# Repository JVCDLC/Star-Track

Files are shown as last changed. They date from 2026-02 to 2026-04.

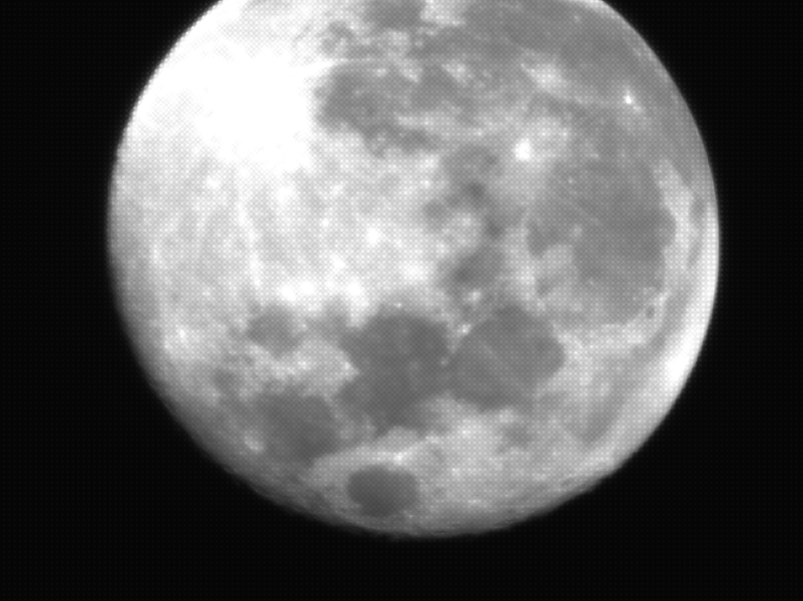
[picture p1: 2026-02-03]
Software/Raspberry Pi/Vision/Sky_Images/lune_2fev/2026-02-03-0417_0-CapObj_0000.PNG

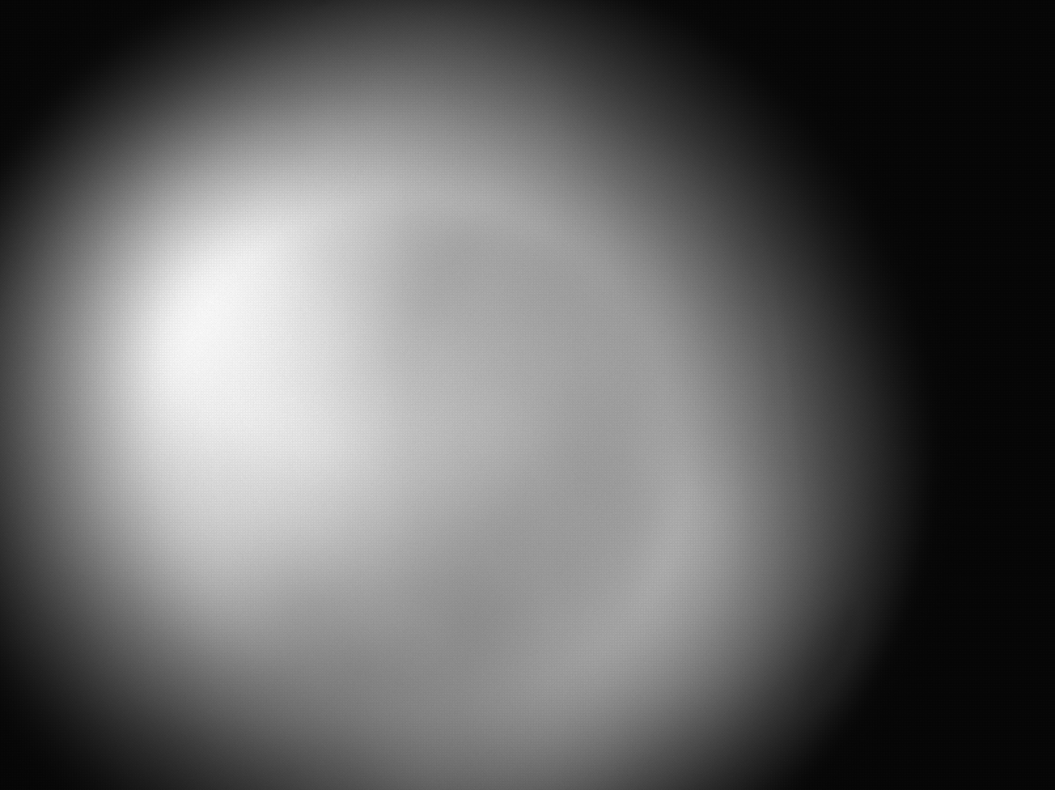
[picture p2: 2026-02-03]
Software/Raspberry Pi/Vision/Sky_Images/lune_2fev/moon_not_focus1.PNG

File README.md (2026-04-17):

# ⭐ Star-Track by JVCDLC

<p align="center">
  Star-Track preview
</p>

## 🚀 Overview

**Star-Track** is an open-source project designed to transform a **manual telescope** into a fully **automated tracking system**.

It enables you to:
- 🔭 Automatically locate stars and planets  
- 🎯 Precisely orient the telescope  
- 🔄 Track celestial objects in real time  
- 🔍 Adjust focus dynamically  

The goal is simple: make astronomical observation **faster, easier, and more accessible**.

---

## 📚 Documentation

All setup instructions, technical details, and recommendations are available in the wiki:

👉 **[Star-Track Wiki](https://github.com/JVCDLC/Star-Track/wiki)**

---

## ⚙️ Features

### 🔧 Calibration
Ensure accurate positioning and alignment of your telescope.

https://github.com/user-attachments/assets/175ef95b-0138-4629-bef2-cc6909bee551

---

### 🌐 Web Interface
Control your telescope from a clean and intuitive interface.

<p align="center">
  Web interface
</p>

---

### 🌌 Celestial Object Alignment
Automatically detect and select stars and planets.

https://github.com/user-attachments/assets/3bd77a46-6f4f-4f7e-8b46-55b38fbb0885

---

### 📡 Tracking
Keep your target centered with continuous real-time tracking.

https://github.com/user-attachments/assets/9ddb90b2-c935-49f4-bd0f-7d9df8abe6cd

---

---

## 📜 License

This project is licensed under the **GNU General Public License v2.0**.

You are free to:
- use
- modify
- distribute

as long as any derivative work is also distributed under the same license.

See the full license here: [LICENSE](./LICENSE)

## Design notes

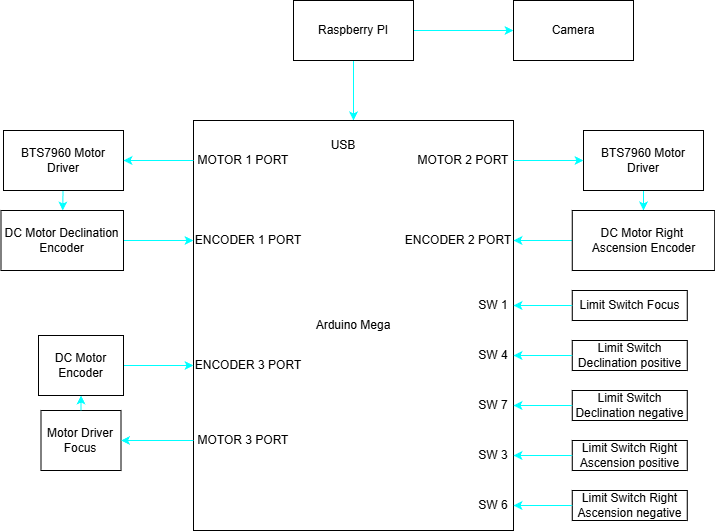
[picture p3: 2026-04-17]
Hardware/Electric shematic.png

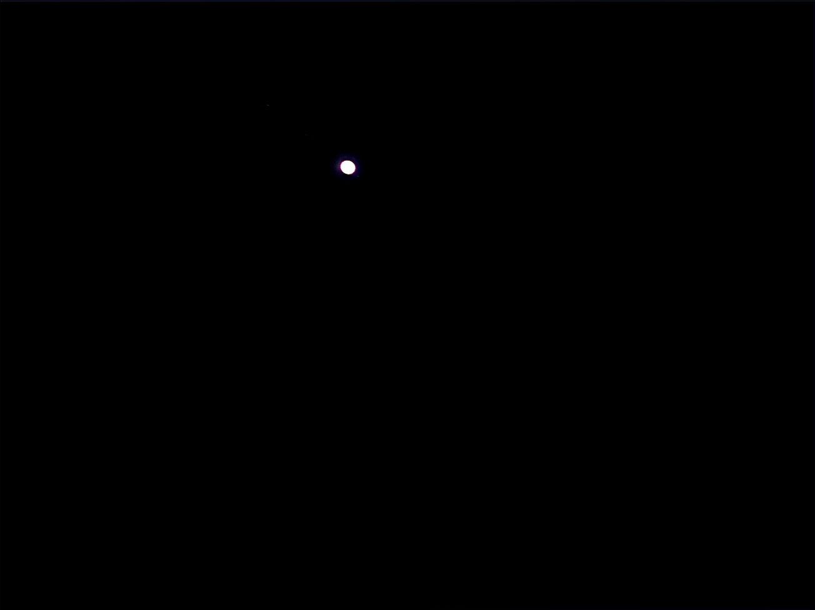
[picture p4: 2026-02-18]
Software/Raspberry Pi/Vision/Sky_Images/jupiter 13 fev/jupiter stack.jpg

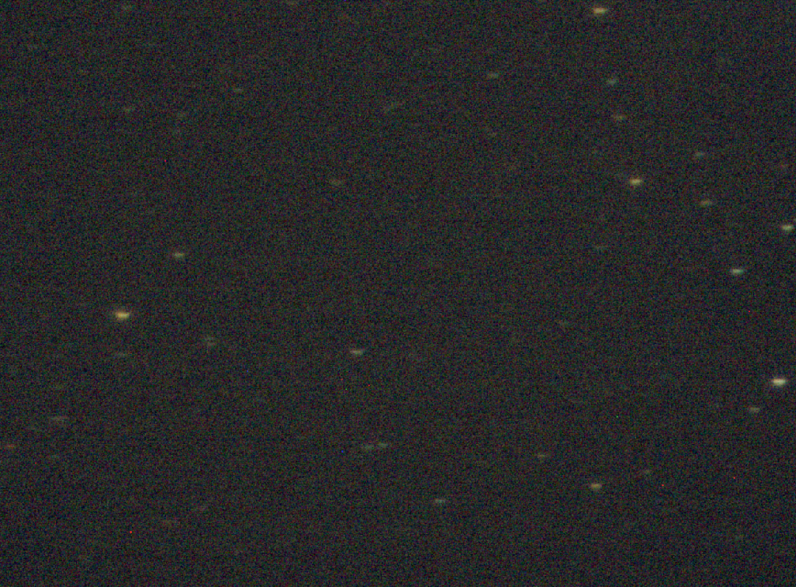
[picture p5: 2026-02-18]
Software/Raspberry Pi/Vision/Sky_Images/ciel etoile 13 fev/Capture d’écran 2026-02-13 010649.png

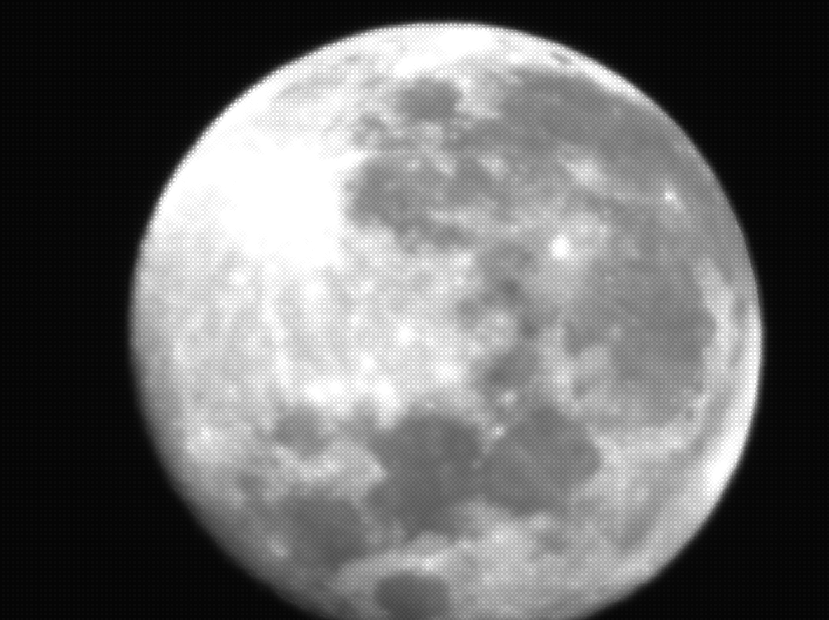
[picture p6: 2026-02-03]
Software/Raspberry Pi/Vision/Sky_Images/lune_2fev/2026-02-03-0418_9-CapObj_0000.PNG

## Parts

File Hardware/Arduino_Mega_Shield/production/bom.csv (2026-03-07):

Designator | Footprint | Quantity | Value | LCSC Part #
A1, A2, A3, A4 | Pololu_Breakout-16_15.2x20.3mm | 4 | Pololu_Breakout_A4988
A5 | Arduino_Mega2560_R3_Shield | 1 | Arduino_Mega2560_R3_Shield
BZ1 | Buzzer_12x9.5RM7.6 | 1 | Buzzer
D1 | LED_D5.0mm-4_RGB_Wide_Pins | 1 | LED_RKGB
J1, J2, J3, J4 | JST_XH_B4B-XH-A_1x04_P2.50mm_Vertical | 4 | Conn_01x04
J11 | PinHeader_1x02_P2.54mm_Vertical | 1 | SW6
J12 | PinHeader_1x02_P2.54mm_Vertical | 1 | SW7
J13 | PinHeader_1x02_P2.54mm_Vertical | 1 | SW8
J14 | PinHeader_1x02_P2.54mm_Vertical | 1 | SW9
J15, J16, J17, J18 | PinHeader_2x04_P2.54mm_Vertical | 4 | Motor Driver Connector
J19 | TerminalBlock_RND_205-00232_1x02_P5.08mm_Horizontal | 1 | Screw_Terminal_01x02
J20 | JST_XH_B4B-XH-A_1x04_P2.50mm_Vertical | 1 | JOYSTICK
J21 | JST_XH_B4B-XH-A_1x04_P2.50mm_Vertical | 1 | I2C CONNECTOR
J22 | JST_XH_B4B-XH-A_1x04_P2.50mm_Vertical | 1 | ENCODER1
J23 | JST_XH_B4B-XH-A_1x04_P2.50mm_Vertical | 1 | ENCODER2
J24 | JST_XH_B4B-XH-A_1x04_P2.50mm_Vertical | 1 | ENCODER3
J25 | JST_XH_B4B-XH-A_1x04_P2.50mm_Vertical | 1 | ENCODER4
J26 | JST_XH_B4B-XH-A_1x04_P2.50mm_Vertical | 1 | UART CONNECTOR
J27, J28, J29, J30, J31, J32, J33, J34, J35, J36, J37, J38 | 3 pin selector | 12 | 3_pin_selector
J39 | PinHeader_1x02_P2.54mm_Vertical | 1 | SW10
J5 | PinHeader_1x02_P2.54mm_Vertical | 1 | SW5
J6 | PinHeader_1x02_P2.54mm_Vertical | 1 | SW1
J7 | PinHeader_1x02_P2.54mm_Vertical | 1 | SW2
J8 | PinHeader_1x02_P2.54mm_Vertical | 1 | SW3
J9 | PinHeader_1x02_P2.54mm_Vertical | 1 | SW4
R1, R10, R2, R3, R4, R5, R6, R7, R8, R9 | R_Axial_DIN0207_L6.3mm_D2.5mm_P7.62mm_Horizontal | 10 | 10kΩ
R11, R12, R13 | R_Axial_DIN0207_L6.3mm_D2.5mm_P7.62mm_Horizontal | 3 | 220Ω

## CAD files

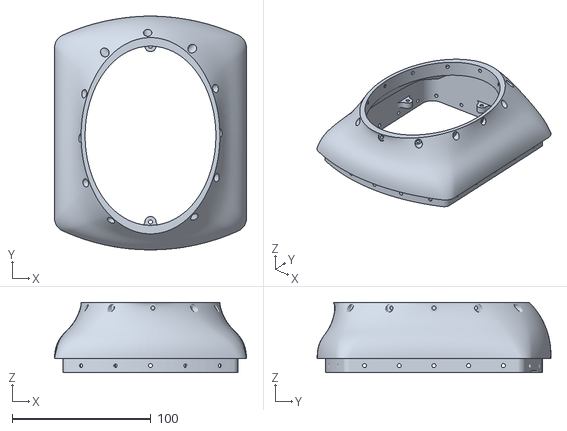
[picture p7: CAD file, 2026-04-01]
3D prints files/009 - TRIPOD BRACKET/LINK MAIN BASE TO MIDDLE ELBOW.stl
138.3 x 168.4 x 50.6

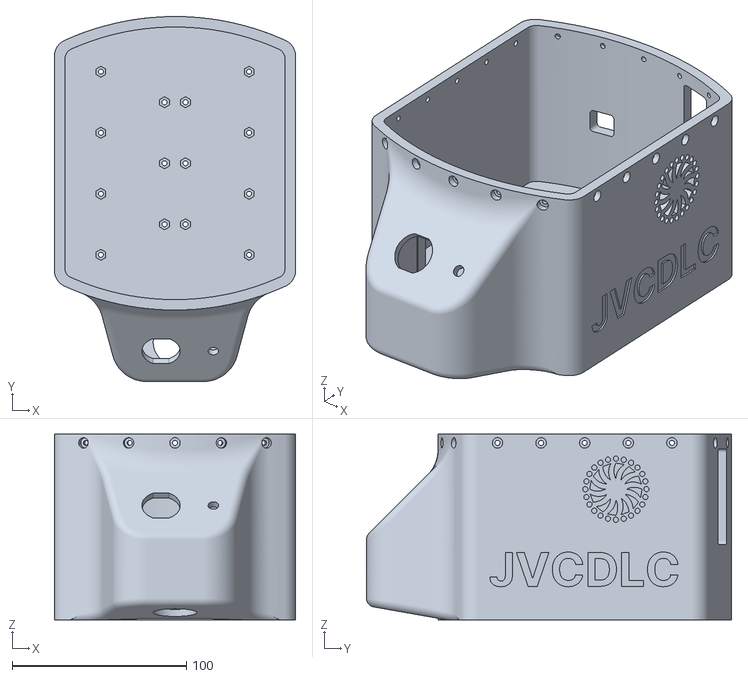
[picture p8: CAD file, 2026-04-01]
3D prints files/009 - TRIPOD BRACKET/MAIN BASE.stl
138.3 x 209.3 x 106.4

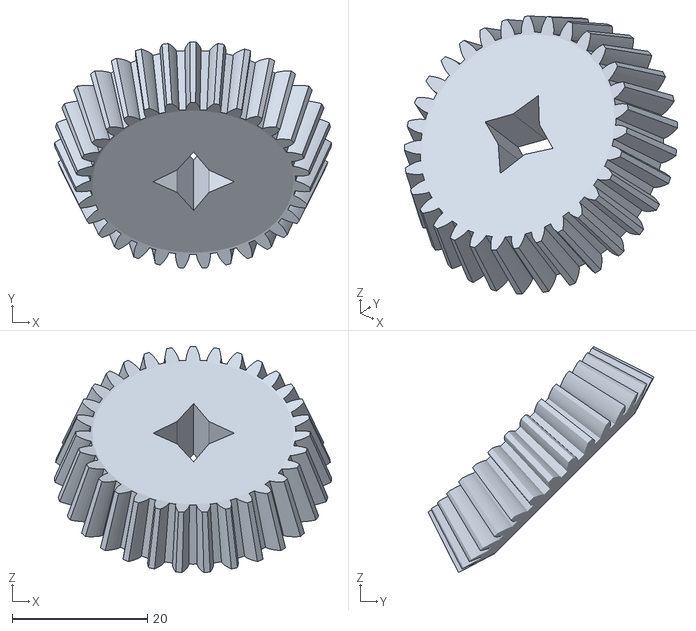
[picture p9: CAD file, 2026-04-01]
3D prints files/005 - FOCUS/MOTOR GEAR.stl
40.9 x 33.4 x 33.4

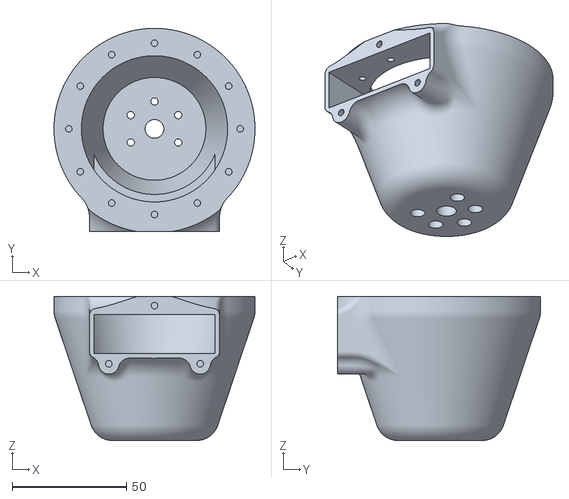
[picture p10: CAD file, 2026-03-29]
3D prints files/007 - GEARBOX JOINT/COUNTER WEIGHT HOLDER.stl
88.0 x 89.0 x 63.1

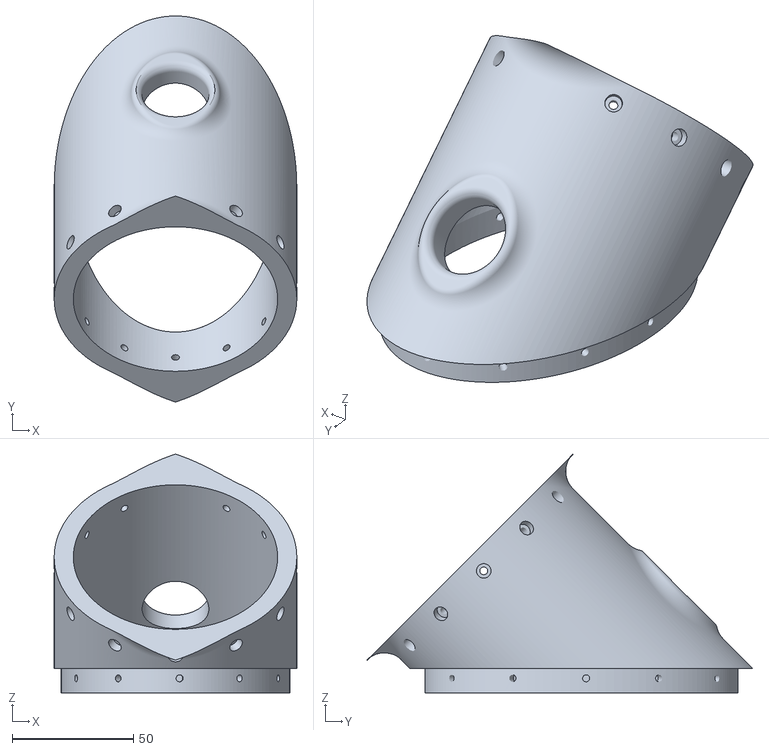
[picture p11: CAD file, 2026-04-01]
3D prints files/009 - TRIPOD BRACKET/MIDDLE BASE ELBOW.stl
100.0 x 159.1 x 98.4

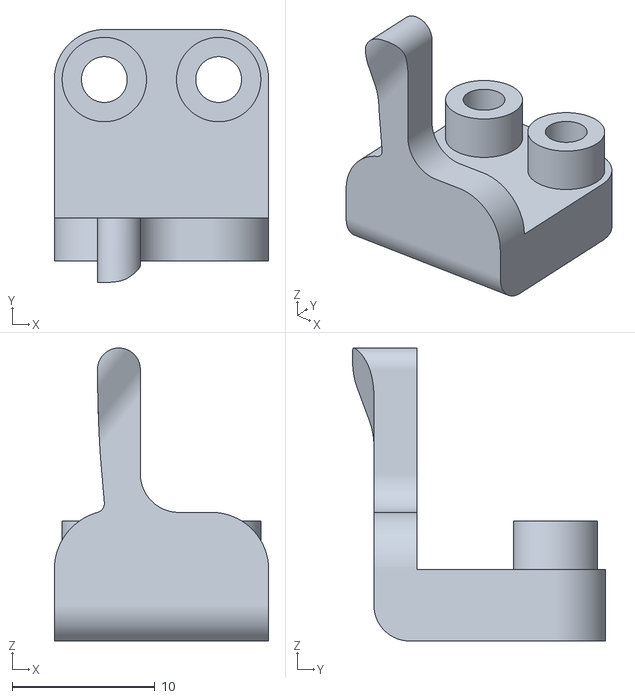
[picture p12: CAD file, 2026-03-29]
3D prints files/012 - LIMIT SWITCH/LEFT STOPPER.stl
15.0 x 17.7 x 20.5

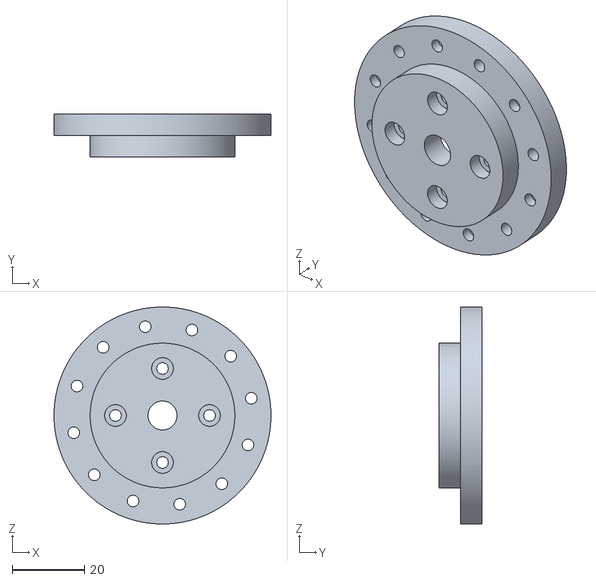
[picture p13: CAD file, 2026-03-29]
3D prints files/014 - CYCLOIDAL GEARBOX/DEC MOTOR MOUNT A.stl
60.0 x 12.0 x 60.0

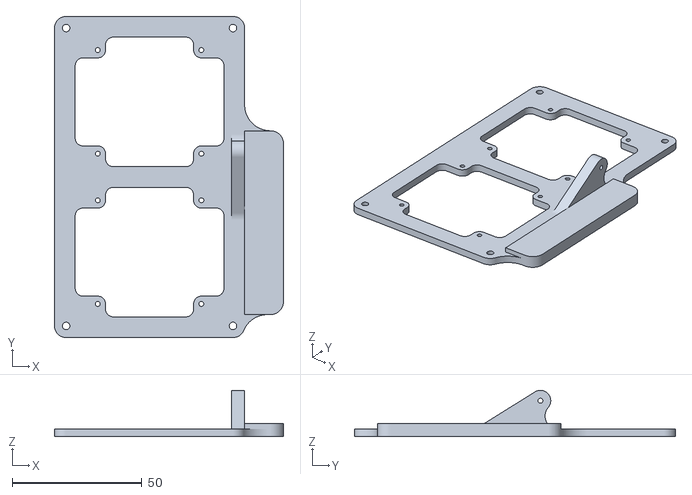
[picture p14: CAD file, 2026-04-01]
3D prints files/015 - ELECTRICAL SKELETON/UPPER PLATE.stl
88.4 x 124.0 x 17.9

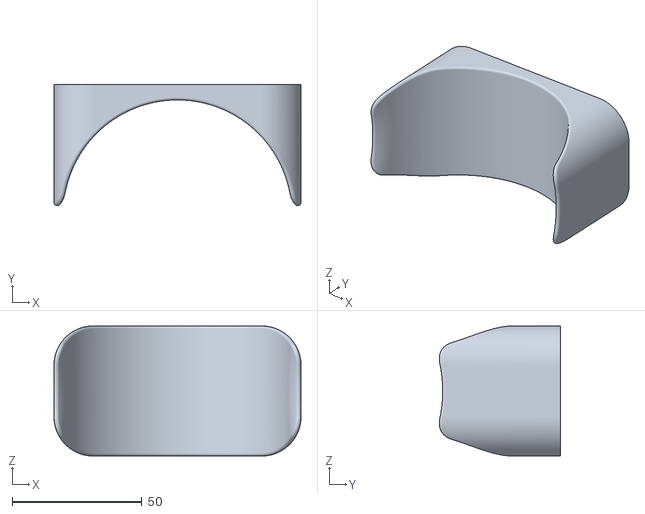
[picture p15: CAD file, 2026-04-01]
3D prints files/OTHER/HOLDER.stl
95.0 x 46.7 x 50.0

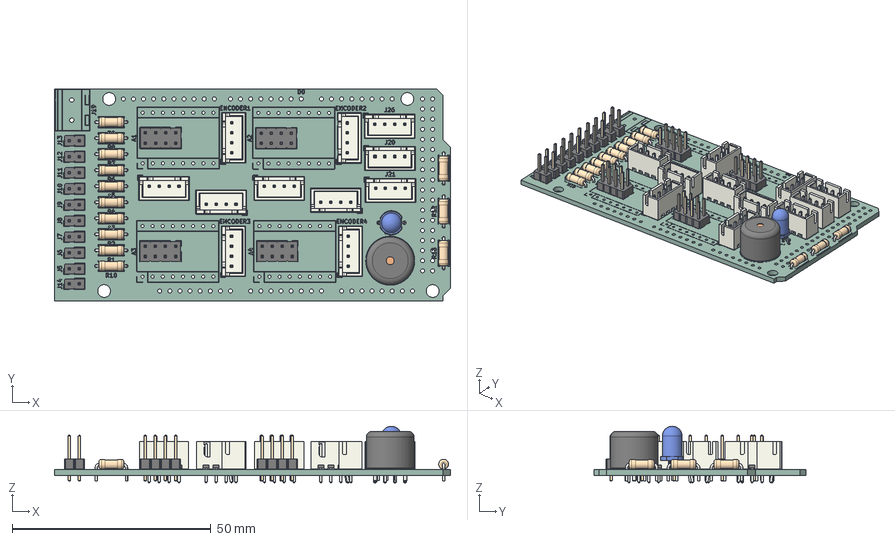
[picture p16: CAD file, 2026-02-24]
Hardware/Arduino_Mega_Shield/Arduino_Mega_Shield.step
99.5 x 53.3 x 14.2 mm
JST_XH_B4B-XH-A_1x04_P2.50mm_Vertical x 11
PinHeader_1x02_P2.54mm_Vertical x 10
LED_D5.0mm-4_RGB_Wide_Pins
R_Axial_DIN0207_L6.3mm_D2.5mm_P7.62mm_Horizontal x 13
PinHeader_2x04_P2.54mm_Vertical x 4
Buzzer_12x9.5RM7.6
Arduino_Mega_Shield_silkscreen x 2
Arduino_Mega_Shield_PCB

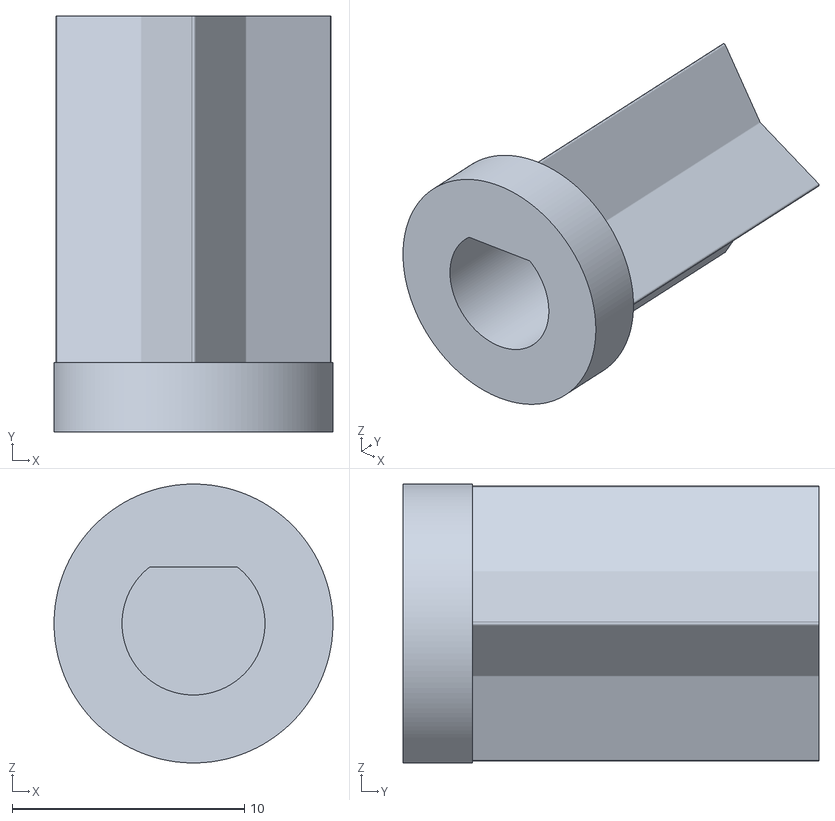
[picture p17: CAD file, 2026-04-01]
3D prints files/005 - FOCUS/SHAFT COUPLING SPLINE.stl
12.0 x 17.9 x 12.0

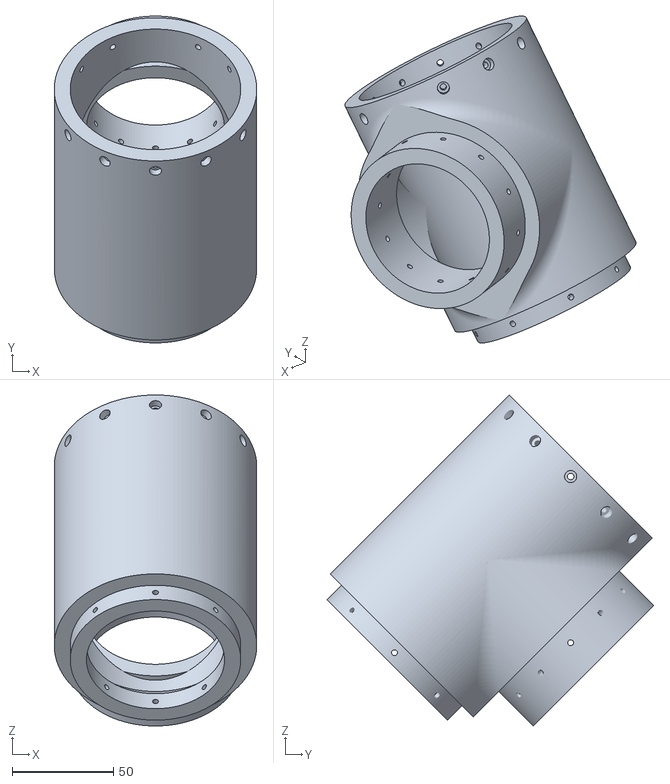
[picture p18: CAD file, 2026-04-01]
3D prints files/009 - TRIPOD BRACKET/ELBOW TO RA GEARBOX.stl
100.0 x 161.4 x 163.5

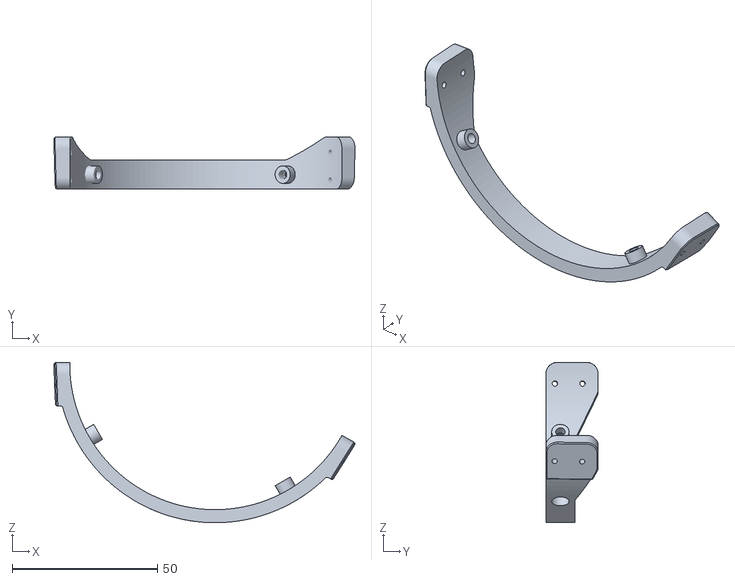
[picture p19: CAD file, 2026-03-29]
3D prints files/012 - LIMIT SWITCH/RA LIMIT SWITCH HOLDER.stl
103.6 x 18.0 x 55.2

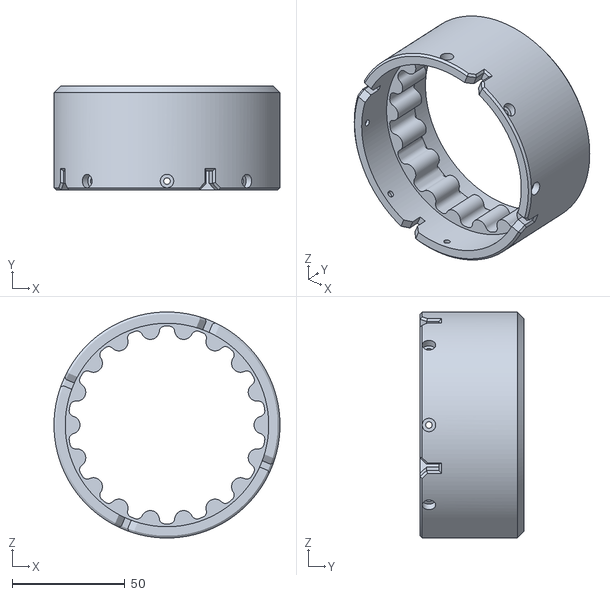
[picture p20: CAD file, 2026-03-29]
3D prints files/014 - CYCLOIDAL GEARBOX/DEC ROTOR.stl
100.0 x 46.1 x 100.0

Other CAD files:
3D prints files/015 - ELECTRICAL SKELETON/LOWER PLATE.stl
3D prints files/OTHER/TELESCOPE MOUNT.stl
3D prints files/005 - FOCUS/FOCUS MOTOR BRACKET.stl
3D prints files/007 - GEARBOX JOINT/BAR HOLDER.stl
3D prints files/005 - FOCUS/FOCUS TELESCOPE BRACKET.stl
3D prints files/005 - FOCUS/TELESCOPE WHEEL GEAR.stl
3D prints files/007 - GEARBOX JOINT/(2X) SIDE COVER PLATE.stl
3D prints files/007 - GEARBOX JOINT/(2X) TOP LOWER PLATE.stl
3D prints files/007 - GEARBOX JOINT/(6X) SCREW BLOCK.stl
3D prints files/007 - GEARBOX JOINT/FRONT COVER PLATE.stl
3D prints files/007 - GEARBOX JOINT/MOUNTING PLATE.stl
3D prints files/009 - TRIPOD BRACKET/ELBOW TO RA GEARBOX JOINT.stl
3D prints files/009 - TRIPOD BRACKET/POWER CABLE PLUG.stl
3D prints files/009 - TRIPOD BRACKET/RA GEARBOX BRACKET.stl
3D prints files/009 - TRIPOD BRACKET/RA MOTOR CAP.stl
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

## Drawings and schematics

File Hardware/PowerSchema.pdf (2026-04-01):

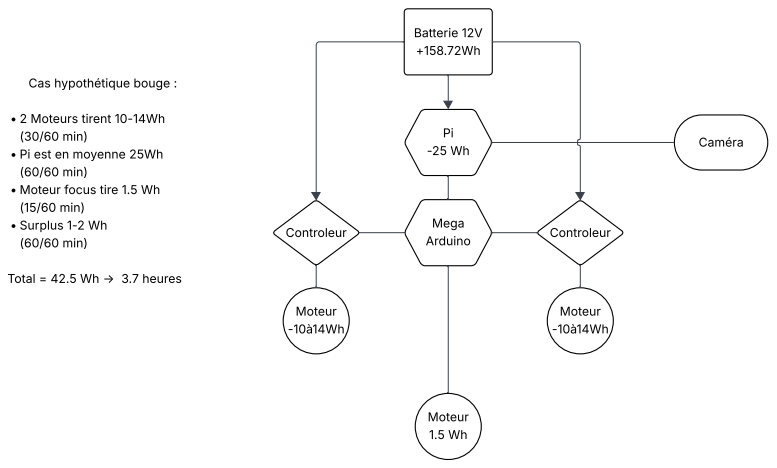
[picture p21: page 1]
Batterie 12V +158.72Wh; Controleur; Moteur -10à14Wh; Moteur 1.5 Wh; Mega Arduino; Caméra

Cas hypothétique bouge :

- 2 Moteurs tirent 10-14Wh
(30/60 min)
- Pi est en moyenne 25Wh
(60/60 min)
- Moteur focus tire 1.5 Wh
(15/60 min)
- Surplus 1-2 Wh

Total = 42.5 Wh ? 3.7 heures

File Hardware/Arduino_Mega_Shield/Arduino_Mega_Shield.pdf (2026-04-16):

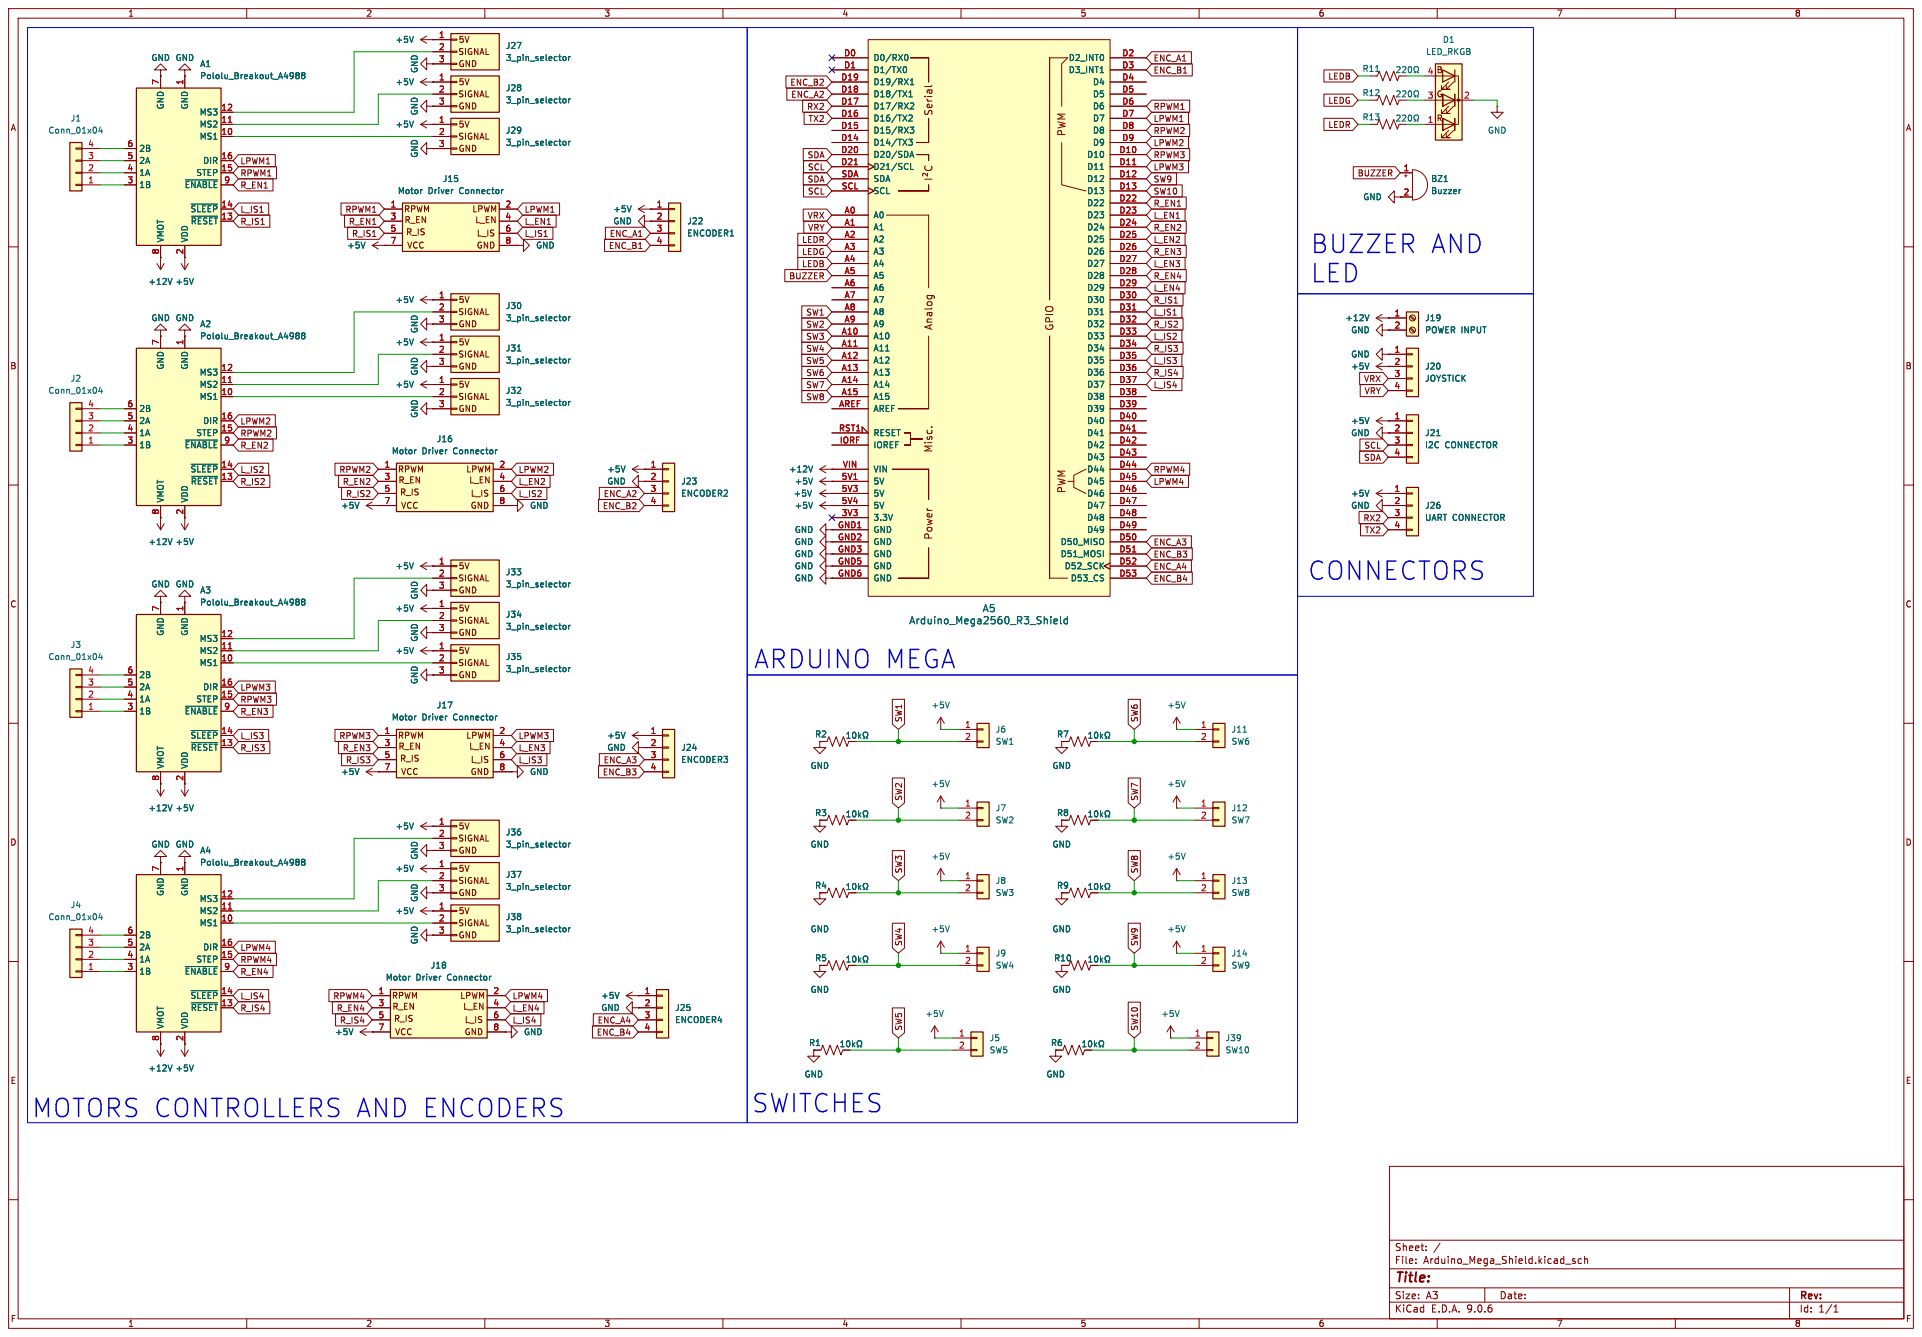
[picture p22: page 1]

GND
BUZZER AND
LED
J19 POWER INPUT GND GND

~{RESET} 13 ~{SLEEP} 14 ~{ENABLE}9 STEP 15 DIR 16 MS1 10 MS2 11 MS3 12 VDD 2 GND 1 VMOT 8 GND 7

J19 POWER INPUT 12 GND GND

A2Pololu_Breakout_A4988 ~{RESET} 13 ~{SLEEP} 14 ~{ENABLE}9 STEP 15 DIR 16 MS1 10 MS2 11 MS3 12 VDD 2 GND 1 VMOT 8 GND 7

J17 Motor Driver Connector GND

3_pin_selector GND GND
A3Pololu_Breakout_A4988 ~{RESET} 13 ~{SLEEP} 14 ~{ENABLE}9 STEP 15 DIR 16 MS1 10 MS2 11 MS3 12 VDD 2 GND 1 VMOT 8 GND 7

Id: 1/1 Title: File: Arduino_Mega_Shield.kicad_sch Sheet: / 12

A4Pololu_Breakout_A4988 ~{RESET} 13 ~{SLEEP} 14 ~{ENABLE}9 STEP 15 DIR 16 MS1 10 MS2 11 MS3 12 VDD 2 GND 1 VMOT 8 GND 7

MOTORS CONTROLLERS AND ENCODERS

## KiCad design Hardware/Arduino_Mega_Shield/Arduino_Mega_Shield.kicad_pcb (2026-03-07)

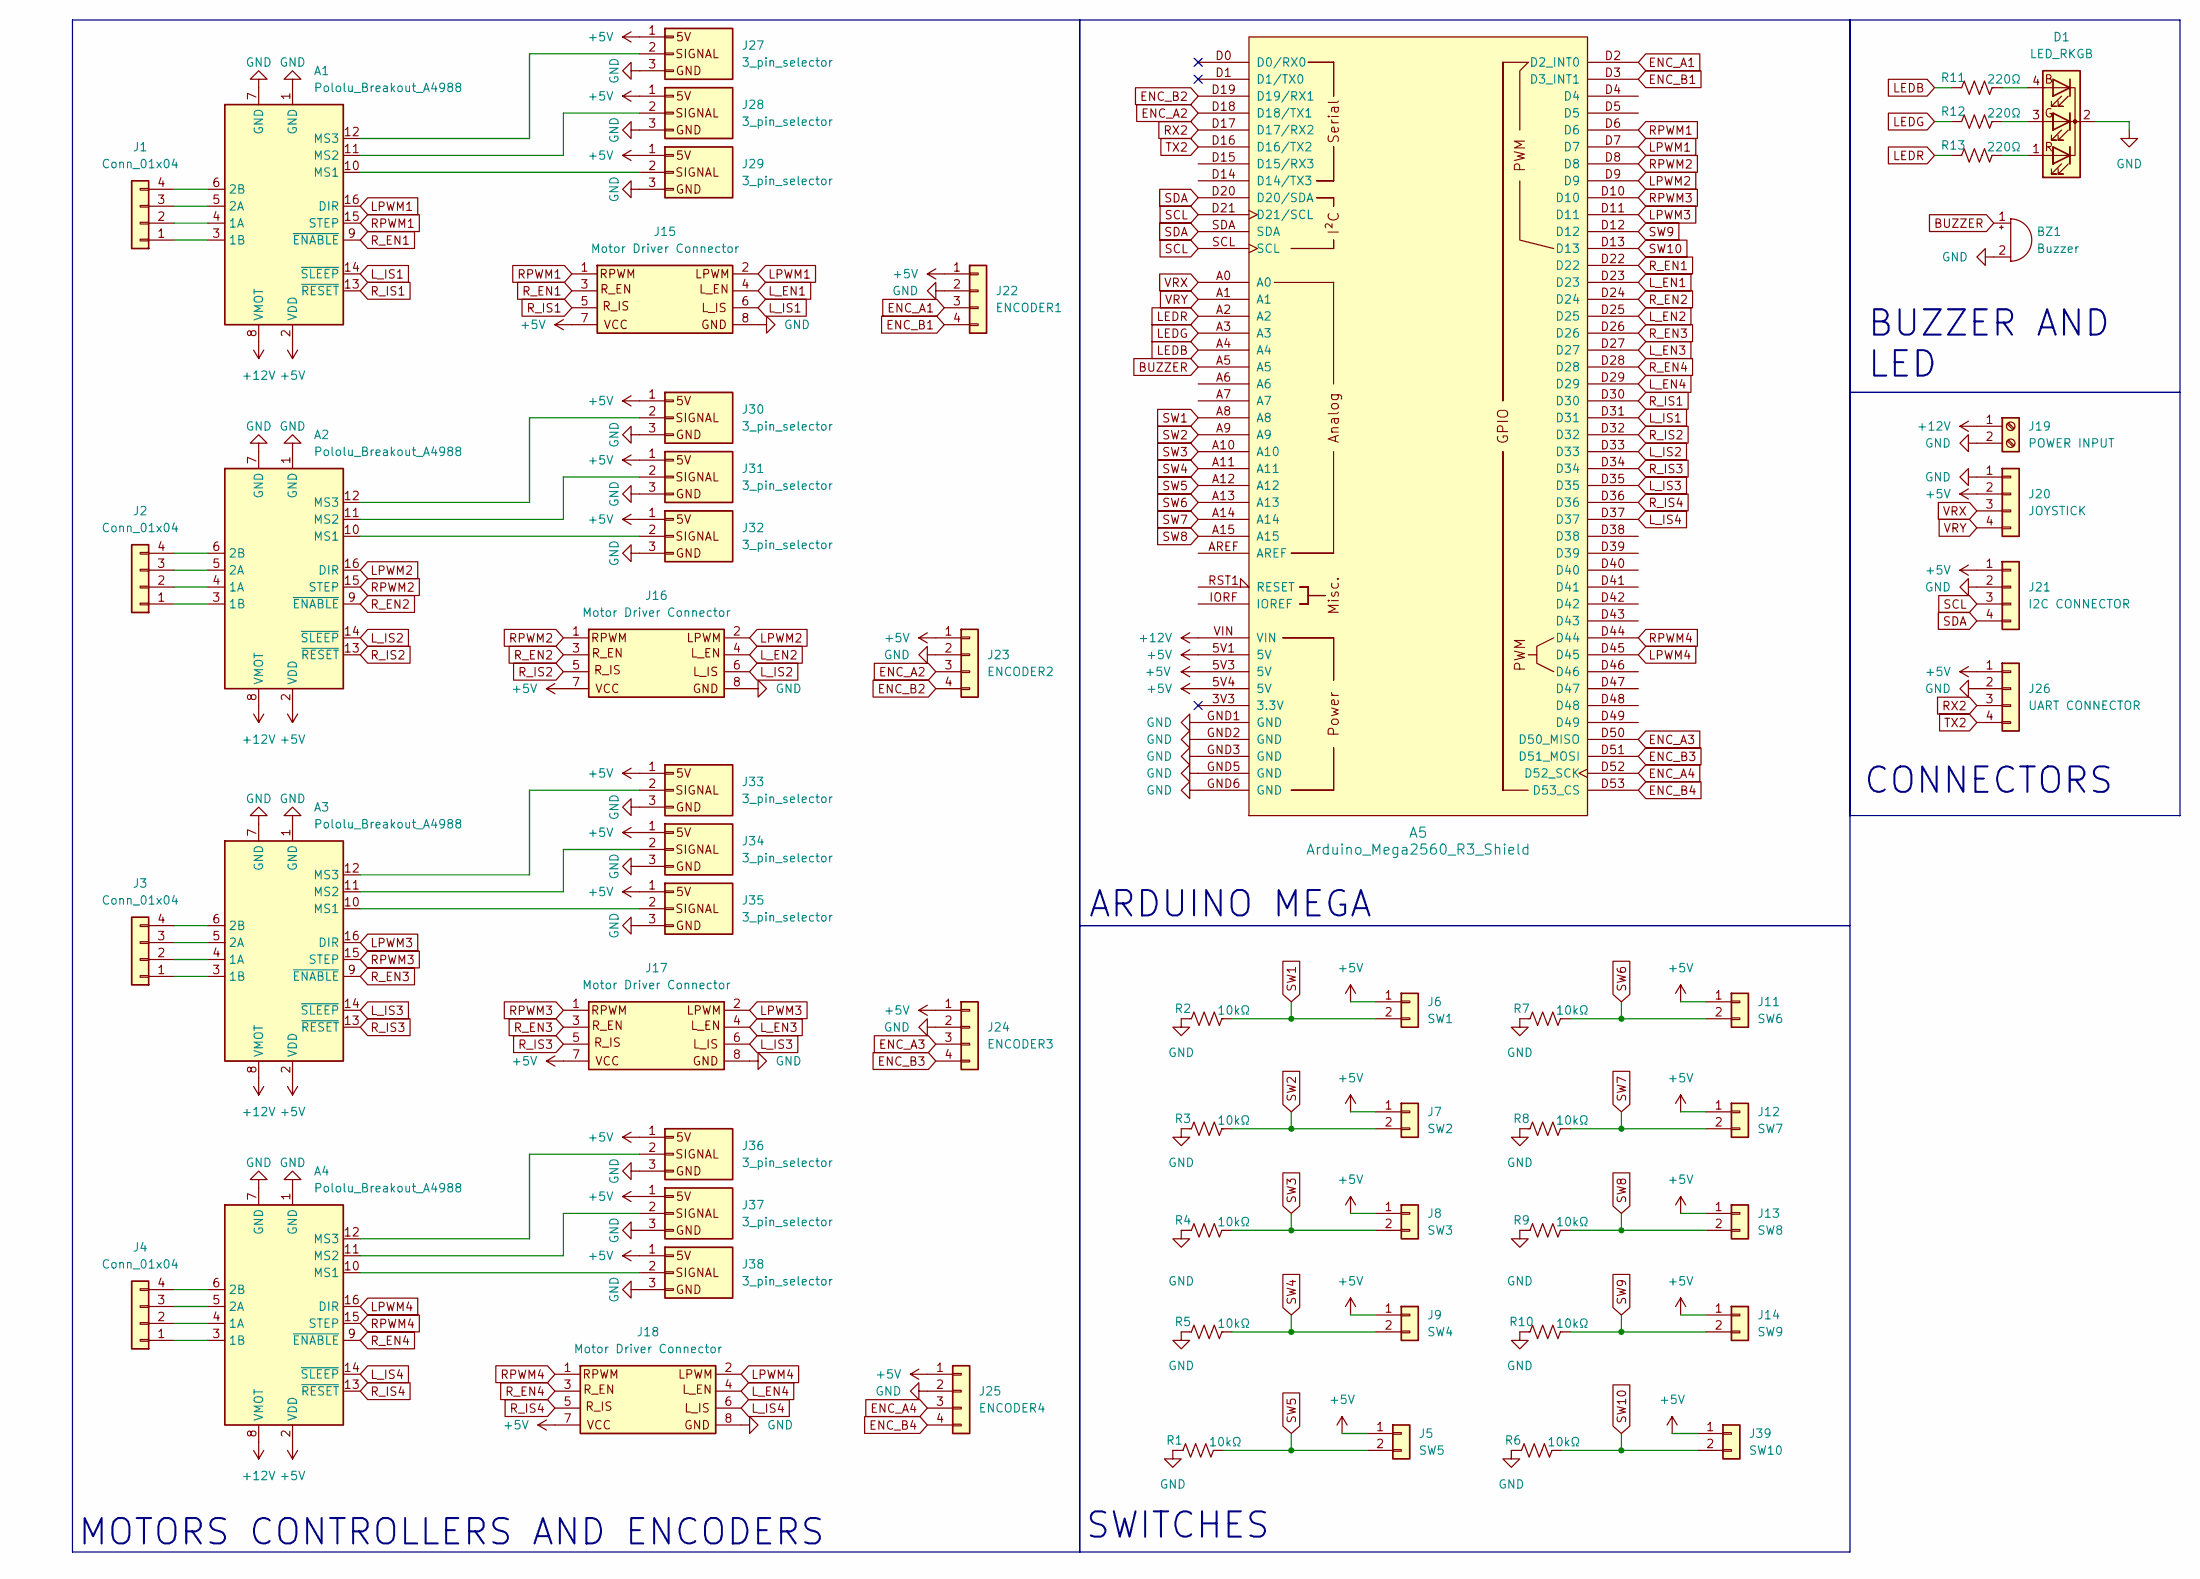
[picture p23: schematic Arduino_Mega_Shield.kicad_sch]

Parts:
A1, A2, A3, A4: Pololu_Breakout_A4988; Pololu_Breakout-16_15.2x20.3mm
A5: Arduino_Mega2560_R3_Shield
BZ1: Buzzer; Buzzer_12x9.5RM7.6
D1: LED_RKGB; LED_D5.0mm-4_RGB_Wide_Pins
J1, J2, J3, J4: Conn_01x04; JST_XH_B4B-XH-A_1x04_P2.50mm_Vertical
J5: SW5; PinHeader_1x02_P2.54mm_Vertical
J6: SW1; PinHeader_1x02_P2.54mm_Vertical
J7: SW2; PinHeader_1x02_P2.54mm_Vertical
J8: SW3; PinHeader_1x02_P2.54mm_Vertical
J9: SW4; PinHeader_1x02_P2.54mm_Vertical
J11: SW6; PinHeader_1x02_P2.54mm_Vertical
J12: SW7; PinHeader_1x02_P2.54mm_Vertical
J13: SW8; PinHeader_1x02_P2.54mm_Vertical
J14: SW9; PinHeader_1x02_P2.54mm_Vertical
J15, J16, J17, J18: Motor Driver Connector; PinHeader_2x04_P2.54mm_Vertical
J19: POWER INPUT; TerminalBlock_RND_205-00232_1x02_P5.08mm_Horizontal
J20: JOYSTICK; JST_XH_B4B-XH-A_1x04_P2.50mm_Vertical
J21: I2C CONNECTOR; JST_XH_B4B-XH-A_1x04_P2.50mm_Vertical
J22: ENCODER1; JST_XH_B4B-XH-A_1x04_P2.50mm_Vertical
J23: ENCODER2; JST_XH_B4B-XH-A_1x04_P2.50mm_Vertical
J24: ENCODER3; JST_XH_B4B-XH-A_1x04_P2.50mm_Vertical
J25: ENCODER4; JST_XH_B4B-XH-A_1x04_P2.50mm_Vertical
J26: UART CONNECTOR; JST_XH_B4B-XH-A_1x04_P2.50mm_Vertical
J27, J28, J29, J30, J31, J32, J33, J34, J35, J36, J37, J38: 3_pin_selector; 3 pin selector
J39: SW10; PinHeader_1x02_P2.54mm_Vertical
R1, R2, R3, R4, R5, R6, R7, R8, R9, R10: 10kΩ; R_Axial_DIN0207_L6.3mm_D2.5mm_P7.62mm_Horizontal
R11, R12, R13: 220Ω; R_Axial_DIN0207_L6.3mm_D2.5mm_P7.62mm_Horizontal

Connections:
+5V: A1.2 (VDD), A2.2 (VDD), A3.2 (VDD), A4.2 (VDD), A5.5V1 (5V), A5.5V3 (5V), A5.5V4 (5V), J5.1, J6.1, J7.1, J8.1, J9.1, J11.1, J12.1, J13.1, J14.1, J15.7, J16.7, J17.7, J18.7, J20.2, J21.1, J22.1, J23.1, J24.1, J25.1, J26.1, J27.1, J28.1, J29.1, J30.1, J31.1, J32.1, J33.1, J34.1, J35.1, J36.1, J37.1, J38.1, J39.1
+12V: A1.8 (VMOT), A2.8 (VMOT), A3.8 (VMOT), A4.8 (VMOT), A5.VIN, J19.1
BUZZER: A5.A5, BZ1.1 (+)
ENC_A1: A5.D2 (D2_INT0), J22.3
ENC_A2: A5.D18 (D18/TX1), J23.3
ENC_A3: A5.D50 (D50_MISO), J24.3
ENC_A4: A5.D52 (D52_SCK), J25.3
ENC_B1: A5.D3 (D3_INT1), J22.4
ENC_B2: A5.D19 (D19/RX1), J23.4
ENC_B3: A5.D51 (D51_MOSI), J24.4
ENC_B4: A5.D53 (D53_CS), J25.4
GND: A1.1 (GND), A1.7 (GND), A2.1 (GND), A2.7 (GND), A3.1 (GND), A3.7 (GND), A4.1 (GND), A4.7 (GND), A5.GND1 (GND), A5.GND2 (GND), A5.GND3 (GND), A5.GND5 (GND), A5.GND6 (GND), BZ1.2 (-), D1.2 (K), J15.8, J16.8, J17.8, J18.8, J19.2, J20.1, J21.2, J22.2, J23.2, J24.2, J25.2, J26.2, J27.3, J28.3, J29.3, J30.3, J31.3, J32.3, J33.3, J34.3, J35.3, J36.3, J37.3, J38.3, R1.1, R2.1, R3.1, R4.1, R5.1, R6.1, R7.1, R8.1, R9.1, R10.1
LEDB: A5.A4, R11.1
LEDG: A5.A3, R12.1
LEDR: A5.A2, R13.1
LPWM1: A1.16 (DIR), A5.D7, J15.2
LPWM2: A2.16 (DIR), A5.D9, J16.2
LPWM3: A3.16 (DIR), A5.D11, J17.2
LPWM4: A4.16 (DIR), A5.D45, J18.2
L_EN1: A5.D23, J15.4
L_EN2: A5.D25, J16.4
L_EN3: A5.D27, J17.4
L_EN4: A5.D29, J18.4
L_IS1: A1.14 (~SLEEP), A5.D31, J15.6
L_IS2: A2.14 (~SLEEP), A5.D33, J16.6
L_IS3: A3.14 (~SLEEP), A5.D35, J17.6
L_IS4: A4.14 (~SLEEP), A5.D37, J18.6
unnamed: A1.4 (1A), J1.2
unnamed: A1.3 (1B), J1.1
unnamed: A1.5 (2A), J1.3
unnamed: A1.6 (2B), J1.4
unnamed: A1.10 (MS1), J29.2
unnamed: A1.11 (MS2), J28.2
unnamed: A1.12 (MS3), J27.2
unnamed: A2.4 (1A), J2.2
unnamed: A2.3 (1B), J2.1
unnamed: A2.5 (2A), J2.3
unnamed: A2.6 (2B), J2.4
unnamed: A2.10 (MS1), J32.2
unnamed: A2.11 (MS2), J31.2
unnamed: A2.12 (MS3), J30.2
unnamed: A3.4 (1A), J3.2
unnamed: A3.3 (1B), J3.1
unnamed: A3.5 (2A), J3.3
unnamed: A3.6 (2B), J3.4
unnamed: A3.10 (MS1), J35.2
unnamed: A3.11 (MS2), J34.2
unnamed: A3.12 (MS3), J33.2
unnamed: A4.4 (1A), J4.2
unnamed: A4.3 (1B), J4.1
unnamed: A4.5 (2A), J4.3
unnamed: A4.6 (2B), J4.4
unnamed: A4.10 (MS1), J38.2
unnamed: A4.11 (MS2), J37.2
unnamed: A4.12 (MS3), J36.2
unnamed: D1.4 (BA), R11.2
unnamed: D1.3 (GA), R12.2
unnamed: D1.1 (RA), R13.2
RPWM1: A1.15 (STEP), A5.D6, J15.1
RPWM2: A2.15 (STEP), A5.D8, J16.1
RPWM3: A3.15 (STEP), A5.D10, J17.1
RPWM4: A4.15 (STEP), A5.D44, J18.1
RX2: A5.D17 (D17/RX2), J26.3
R_EN1: A1.9 (~ENABLE), A5.D22, J15.3
R_EN2: A2.9 (~ENABLE), A5.D24, J16.3
R_EN3: A3.9 (~ENABLE), A5.D26, J17.3
R_EN4: A4.9 (~ENABLE), A5.D28, J18.3
R_IS1: A1.13 (~RESET), A5.D30, J15.5
R_IS2: A2.13 (~RESET), A5.D32, J16.5
R_IS3: A3.13 (~RESET), A5.D34, J17.5
R_IS4: A4.13 (~RESET), A5.D36, J18.5
SCL: A5.D21 (D21/SCL), A5.SCL, J21.3
SDA: A5.D20 (D20/SDA), A5.SDA, J21.4
SW1: A5.A8, J6.2, R2.2
SW2: A5.A9, J7.2, R3.2
SW3: A5.A10, J8.2, R4.2
SW4: A5.A11, J9.2, R5.2
SW5: A5.A12, J5.2, R1.2
SW6: A5.A13, J11.2, R7.2
SW7: A5.A14, J12.2, R8.2
SW8: A5.A15, J13.2, R9.2
SW9: A5.D12, J14.2, R10.2
SW10: A5.D13, J39.2, R6.2
TX2: A5.D16 (D16/TX2), J26.4
VRX: A5.A0, J20.3
VRY: A5.A1, J20.4

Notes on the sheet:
SWITCHES
BUZZER AND LED
MOTORS CONTROLLERS AND ENCODERS
CONNECTORS
ARDUINO MEGA

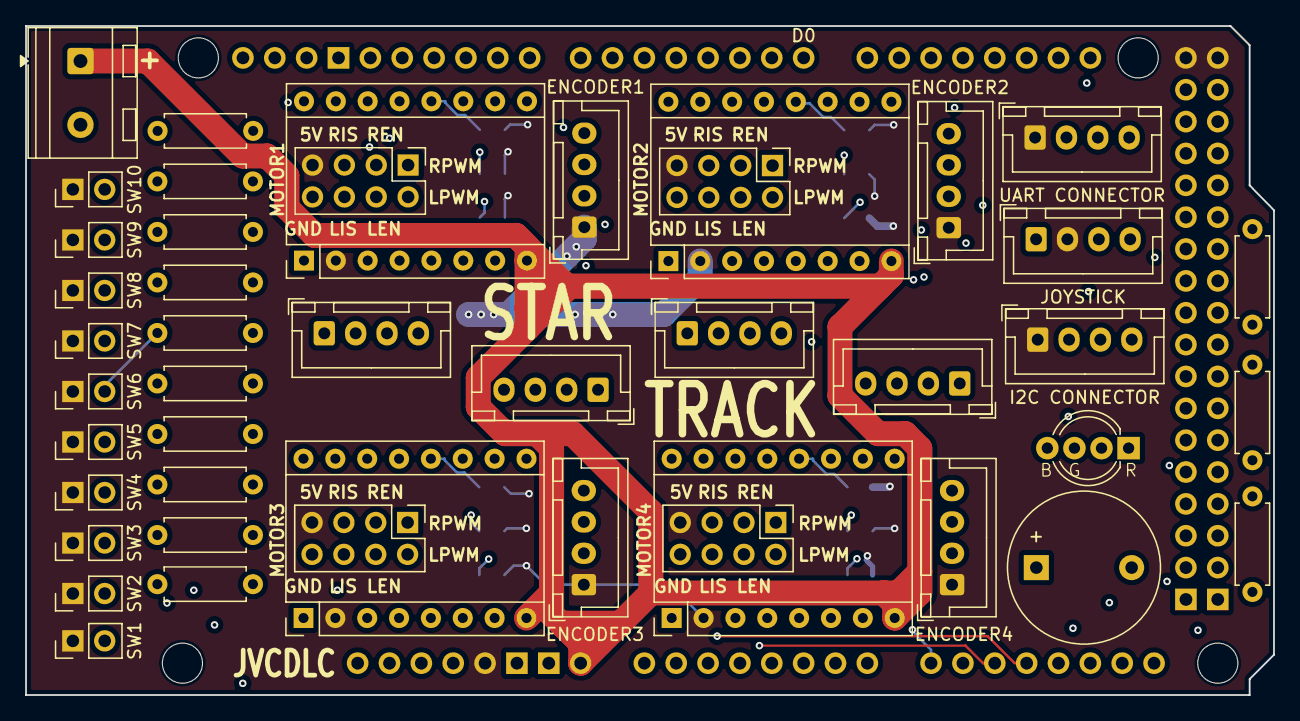
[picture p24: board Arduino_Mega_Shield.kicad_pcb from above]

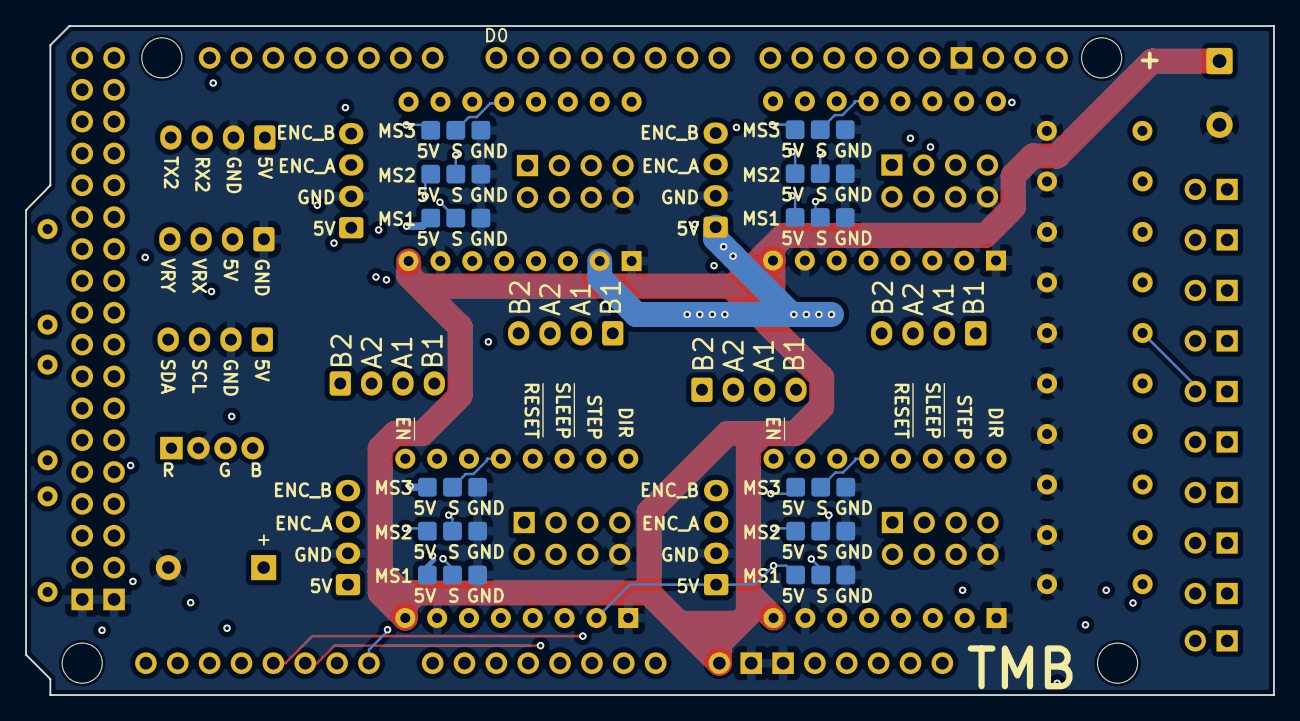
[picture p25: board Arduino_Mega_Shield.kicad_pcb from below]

Board: 4 copper layers, 99.5 x 53.3 mm, 58 parts (12 on the bottom side), 86 nets.

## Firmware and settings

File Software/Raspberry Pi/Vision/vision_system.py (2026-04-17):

"""
Star-Track vision/autofocus runtime (standalone utility).

This module provides:
1) frame processing (target center + focus score),
2) autofocus sweep analysis over multiple passes,
3) an Arduino bridge with optional physics simulation,
4) a display loop that correlates frame and motor step.

The comments in this file are intentionally operational and maintenance-focused,
so the calibration/tracking flow is easy to debug without changing behavior.
"""

import cv2
import numpy as np
import zmq
import time
import threading
import queue
import serial
from pathlib import Path
try:
    from serial.tools import list_ports
except Exception:
    list_ports = None

# ==========================================
# SYSTEM CONSTANTS
# ==========================================
TOTAL_MOTOR_STEPS = 10116  # Total physical steps of the sweep range
VIDEO_WIDTH = 640
VIDEO_HEIGHT = 480
UI_HEIGHT = 150
SIM_VIDEO_DEFAULT = Path(__file__).resolve().parents[1] / "WebUI" / "simulation.mp4"

def draw_hud(data, current_step, state, focus_score, current_frame):
    """
    Build the lower diagnostic panel shown under the live frame.

    Interaction notes:
    - Uses the autofocus sample history (`data`) to draw a focus curve.
    - Uses `current_step` to place a red vertical marker on that curve.
    - Shows state-machine text so operators can correlate motion with analysis.
    """
    ui = np.zeros((UI_HEIGHT, VIDEO_WIDTH, 3), dtype=np.uint8)
    
    # Grid lines and UI background
    cv2.rectangle(ui, (0, 0), (VIDEO_WIDTH, UI_HEIGHT), (20, 20, 20), -1)
    cv2.line(ui, (0, 0), (VIDEO_WIDTH, 0), (255, 255, 255), 2)
    
    # Text Information (Left side)
    cv2.putText(ui, f"State: {state}", (10, 25), cv2.FONT_HERSHEY_SIMPLEX, 0.6, (0, 255, 0), 2)
    cv2.putText(ui, f"Motor Step: {current_step:.1f} / {TOTAL_MOTOR_STEPS:.0f}", (10, 55), cv2.FONT_HERSHEY_SIMPLEX, 0.6, (0, 255, 255), 2)
    cv2.putText(ui, f"Video Frame: {current_frame}", (10, 85), cv2.FONT_HERSHEY_SIMPLEX, 0.6, (255, 100, 100), 2)
    cv2.putText(ui, f"Focus Score: {focus_score:.1f}", (10, 115), cv2.FONT_HERSHEY_SIMPLEX, 0.6, (255, 255, 0), 2)
    
    # Graph Drawing (Right side)
    g_x, g_y = 300, 20
    g_w, g_h = VIDEO_WIDTH - g_x - 20, UI_HEIGHT - 40
    cv2.rectangle(ui, (g_x, g_y), (g_x + g_w, g_y + g_h), (40, 40, 40), -1)
    
    if len(data) >= 2:
        steps = [d[0] for d in data]
        scores = [d[1] for d in data]
        min_s, max_s = min(steps), max(steps)
        max_score = max(scores) if max(scores) > 0 else 1
        
        # Plot curve
        for i in range(1, len(data)):
            x1 = int(g_x + ((steps[i-1] - min_s) / (max_s - min_s + 1e-5)) * g_w)
            y1 = int(g_y + g_h - (scores[i-1] / max_score) * g_h)
            x2 = int(g_x + ((steps[i] - min_s) / (max_s - min_s + 1e-5)) * g_w)
            y2 = int(g_y + g_h - (scores[i] / max_score) * g_h)
            cv2.line(ui, (x1, y1), (x2, y2), (0, 255, 255), 2)
            
        # Draw current position marker (Red Line)
        if min_s <= current_step <= max_s:
            cx = int(g_x + ((current_step - min_s) / (max_s - min_s + 1e-5)) * g_w)
            cv2.line(ui, (cx, g_y), (cx, g_y + g_h), (0, 0, 255), 2)
            
    cv2.putText(ui, "Focus Graph", (g_x, g_y - 5), cv2.FONT_HERSHEY_SIMPLEX, 0.4, (200, 200, 200), 1)
    return ui

def put_text_outline(img, text, pos, color=(0, 255, 0)):
    """
    Draw text with an outline to stay legible against bright stars/noise.

    The function always draws twice:
    1) thick black stroke,
    2) colored foreground.
    """
    cv2.putText(img, text, pos, cv2.FONT_HERSHEY_SIMPLEX, 0.7, (0, 0, 0), 3) # Outline
    cv2.putText(img, text, pos, cv2.FONT_HERSHEY_SIMPLEX, 0.7, color, 2)     # Inner

# ==========================================
# 1. VISION PROCESSING
# ==========================================
class VisionProcessor:
    def __init__(self, scale=0.5):
        """
        Create the frame processor.

        `scale` controls downsampling before contour/focus analysis:
        lower values are faster, higher values keep more detail.
        """
        self.scale = scale

    def process_frame(self, frame):
        """
        Process one frame and return:
        - annotated frame copy,
        - scalar focus score,
        - detected target center in full-resolution coordinates (or None).

        Pipeline:
        1) resize and grayscale,
        2) blur + Otsu threshold + morphology for robust blob mask,
        3) largest contour center extraction,
        4) Laplacian variance focus metric over masked region.
        """
        # Normalize input resolution first so downstream thresholds stay consistent.
        # Force frame to standard size for consistency
        frame = cv2.resize(frame, (VIDEO_WIDTH, VIDEO_HEIGHT))
        original = frame.copy()
        
        small = cv2.resize(frame, None, fx=self.scale, fy=self.scale)
        gray = cv2.cvtColor(small, cv2.COLOR_BGR2GRAY)
        blurred = cv2.GaussianBlur(gray, (5, 5), 1.5)

        _, mask = cv2.threshold(blurred, 0, 255, cv2.THRESH_BINARY + cv2.THRESH_OTSU)
        kernel = np.ones((5, 5), np.uint8)
        mask = cv2.morphologyEx(mask, cv2.MORPH_CLOSE, kernel)

        contours, _ = cv2.findContours(mask, cv2.RETR_EXTERNAL, cv2.CHAIN_APPROX_SIMPLE)
        center = None

        if contours:
            largest = max(contours, key=cv2.contourArea)
            (x, y), radius = cv2.minEnclosingCircle(largest)
            center = (int(x / self.scale), int(y / self.scale))
            cv2.circle(original, center, 5, (0, 0, 255), -1)

        laplacian = cv2.Laplacian(gray, cv2.CV_64F)
        if np.any(mask > 0):
            focus_score = np.var(laplacian[mask > 0])
        else:
            focus_score = 0.0

        return original, focus_score, center

# ==========================================
# 2. AUTOFOCUS ANALYZER
# ==========================================
class AutofocusAnalyzer:
    def __init__(self, threshold_ratio=0.5, smoothing_window=5):
        """
        Hold sweep samples and compute best-focus positions.

        `threshold_ratio` and `smoothing_window` tune how aggressive pass-2
        narrowing is around the peak.
        """
        self.data =[]  
        self.threshold_ratio = threshold_ratio
        self.smoothing_window = smoothing_window

    def add_data_point(self, step, focus_score):
        """Append one sample pair `(axis_position, focus_score)` to current pass history."""
        self.data.append((step, focus_score))

    def analyze_sweep(self, pass_number):
        """
        Analyze collected samples and return `(best_step, (start_step, end_step))`.

        Pass behavior:
        - pass 1: broad coarse window around peak,
        - pass 2: threshold-ratio based narrowing around peak,
        - pass 3+: lock directly on best step.
        """
        if len(self.data) < self.smoothing_window:
            return None, None

        self.data.sort(key=lambda x: x[0]) 
        steps = np.array([x[0] for x in self.data])
        scores = np.array([x[1] for x in self.data])

        kernel = np.ones(self.smoothing_window) / self.smoothing_window
        smoothed_scores = np.convolve(scores, kernel, mode='valid')
        
        trim = self.smoothing_window // 2
        valid_steps = steps[trim : -trim]
        if len(valid_steps) == 0: valid_steps = steps 

        max_idx = np.argmax(smoothed_scores)
        best_step = valid_steps[max_idx]
        
        if pass_number == 1:
            left_side = smoothed_scores[:max_idx]
            right_side = smoothed_scores[max_idx:]
            start_step = valid_steps[np.argmin(left_side)] if len(left_side) > 0 else valid_steps[0]
            end_step = valid_steps[max_idx + np.argmin(right_side)] if len(right_side) > 0 else valid_steps[-1]
            
        elif pass_number == 2:
            max_score = smoothed_scores[max_idx]
            threshold = max_score * self.threshold_ratio
            left_side = smoothed_scores[:max_idx]
            start_step = valid_steps[np.where(left_side < threshold)[0][-1]] if np.any(left_side < threshold) else valid_steps[0]
            right_side = smoothed_scores[max_idx:]
            end_step = valid_steps[max_idx + np.where(right_side < threshold)[0][0]] if np.any(right_side < threshold) else valid_steps[-1]
            
        else:
            start_step, end_step = best_step, best_step

        return float(best_step), (float(min(start_step, end_step)), float(max(start_step, end_step)))

    def reset(self):
        """Clear pass samples before starting a new sweep segment."""
        self.data =[]

    def analyze_timed_sweep(self, pass_number, start_step, target_step, start_time, end_time):
        """
        Convert (timestamp, focus_score) samples to estimated motor steps using the measured
        sweep duration, then reuse the standard pass analysis.
        """
        duration = max(1e-3, float(end_time) - float(start_time))
        distance = float(target_step) - float(start_step)

        converted = []
        for ts, score in self.data:
            ratio = (float(ts) - float(start_time)) / duration
            ratio = max(0.0, min(1.0, ratio))
            est_step = float(start_step) + (distance * ratio)
            converted.append((est_step, score))

        self.data = converted
        return self.analyze_sweep(pass_number), duration

# ==========================================
# 3. HARDWARE CONTROLLER (DUAL PID PHYSICS)
# ==========================================
class PID:
    def __init__(self, kp, ki, kd, out_max):
        """
        Generic PID container used by simulation-only motion models.

        - `out_max` caps command magnitude to keep simulation stable.
        """
        self.kp = kp
        self.ki = ki
        self.kd = kd
        self.out_max = out_max
        self.integral = 0.0
        self.prev_error = 0.0

    def compute(self, error, dt):
        """
        Compute PID output for current error/time-step.

        The result is saturated to `[-out_max, +out_max]`.
        """
        self.integral += error * dt
        derivative = (error - self.prev_error) / dt if dt > 0 else 0
        self.prev_error = error
        output = (self.kp * error) + (self.ki * self.integral) + (self.kd * derivative)
        return max(-self.out_max, min(self.out_max, output))

class ArduinoController:
    def __init__(self, simulate=False, port='auto', baudrate=115200):
        """
        Focus-axis bridge:
        - hardware mode: send/receive serial commands from Arduino firmware,
        - simulation mode: emulate position/speed behavior with dual PID physics.
        """
        self.simulate = simulate
        self.cmd_queue = queue.Queue()
        self.response_queue = queue.Queue()
        self.running = True

        # Simulation state mirrors focus-axis behavior in "good enough" physics terms.
        # --- Simulated Physics State ---
        self.current_pos = 0.0
        self.current_vel = 0.0
        self.target_pos = 0.0
        self.target_speed = 0.0
        self.start_pos = 0.0
        self.state = "IDLE"  
        
        # Dual PID Control
        # Position PID (Outputs Target Speed)
        self.pos_pid = PID(kp=4.0, ki=0.0, kd=0.1, out_max=800.0)
        # Speed PID (Outputs Acceleration)
        self.vel_pid = PID(kp=3.0, ki=0.5, kd=0.05, out_max=2000.0) 

        if not self.simulate:
            if port in (None, "", "auto"):
                port = self._detect_port()
            try:
                self.ser = serial.Serial(port, baudrate, timeout=1)
            except Exception as e:
                print(f"Error opening serial port: {e}. Falling back to simulation.")
                self.simulate = True

        self.thread = threading.Thread(target=self._worker, daemon=True)
        self.thread.start()

    def _detect_port(self):
        """Pick the most likely Arduino serial port from available devices."""
        # Auto-select best candidate serial port when explicit port is not provided.
        if list_ports is None:
            return '/dev/ttyUSB0'
        ports = list(list_ports.comports())
        if not ports:
            return '/dev/ttyUSB0'
        def score(p):
            """
            Rank serial-port candidates so Arduino-like devices are selected first.
            """
            text = " ".join([str(p.device), str(p.description), str(p.hwid)]).lower()
            s = 0
            if "arduino" in text: s += 20
            if "ch340" in text or "wch" in text: s += 15
            if "usb serial" in text or "ttyusb" in text or "ttyacm" in text: s += 10
            if str(p.device).upper().startswith("COM"): s += 5
            return s
        return sorted(ports, key=score, reverse=True)[0].device

    def get_current_position(self):
        """Return current focus position estimate (ticks)."""
        return self.current_pos

    def send_command(self, action, motor, value="", value2=""):
        """
        Queue a command using the same CSV protocol as the refactored firmware.

        Examples:
        - `1,FOC,<target_ticks>`
        - `2,FOC,<target_ticks>,<ticks_per_second>`
        """
        if value2 != "":
            cmd_str = f"{action},{motor},{value},{value2}"
        else:
            cmd_str = f"{action},{motor},{value}"
        self.cmd_queue.put(cmd_str)
        print(f"[Arduino TX] {cmd_str}")

    def check_response(self):
        """Non-blocking pop of the latest Arduino response code ('0'/'1'/'2')."""
        try:
            return self.response_queue.get_nowait()
        except queue.Empty:
            return None

    def _worker(self):
        """
        Background execution loop.

        Responsibilities:
        - consume queued commands,
        - step simulation physics (when simulate=True),
        - forward serial I/O and acknowledgments (when simulate=False),
        - keep command/response timing deterministic enough for autofocus tests.
        """
        # Single background worker for both hardware IO and simulation stepping.
        last_time = time.time()
        
        while self.running:
            current_time = time.time()
            dt = max(0.001, current_time - last_time)
            last_time = current_time

            if not self.cmd_queue.empty() and self.state == "IDLE":
                cmd = self.cmd_queue.get()
                
                if self.simulate:
                    parts = cmd.split(',')
                    action = int(parts[0])
                    
                    if action == 1:
                        # Cmd 1: Move to Position (Uses Position -> Speed PID)
                        self.target_pos = float(parts[2])
                        self.pos_pid.integral = 0
                        self.vel_pid.integral = 0
                        self.state = "PID_MOVE"
                        self.response_queue.put("1")  # accepted
                        
                    elif action == 2:
                        # Cmd 2 (refactored protocol): 2,FOC,<target_ticks>,<ticks_per_second>
                        self.target_pos = float(parts[2])
                        self.target_speed = float(parts[3])
                        self.start_pos = self.current_pos
                        self.vel_pid.integral = 0
                        self.state = "SWEEP_MOVE"
                        self.response_queue.put("1")  # accepted
                else:
                    self.ser.write((cmd + '\n').encode('utf-8'))

            # --- PHYSICS ENGINE UPDATE ---
            if self.simulate:
                if self.state == "PID_MOVE":
                    # Cascade: Position Error -> Target Velocity
                    pos_err = self.target_pos - self.current_pos
                    target_vel = self.pos_pid.compute(pos_err, dt)
                    
                    # Cascade: Velocity Error -> Acceleration
                    vel_err = target_vel - self.current_vel
                    accel = self.vel_pid.compute(vel_err, dt)
                    
                    self.current_vel += accel * dt
                    self.current_pos += self.current_vel * dt
                    
                    # Arrival logic (Close enough & not moving fast)
                    if abs(pos_err) < 1.0 and abs(self.current_vel) < 5.0:
                        self.current_pos = self.target_pos
                        self.current_vel = 0.0
                        self.state = "IDLE"
                        self.response_queue.put("2")
                        print("[Arduino RX - SIM] 2")

                elif self.state == "SWEEP_MOVE":
                    direction = 1 if self.target_pos > self.start_pos else -1
                    target_vel = self.target_speed * direction
                    
                    # Speed PID to Acceleration
                    vel_err = target_vel - self.current_vel
                    accel = self.vel_pid.compute(vel_err, dt)
                    
                    self.current_vel += accel * dt
                    self.current_pos += self.current_vel * dt
                    
                    # Immediate stop upon crossing Endpoint
                    if (direction == 1 and self.current_pos >= self.target_pos) or \
                       (direction == -1 and self.current_pos <= self.target_pos):
                        self.current_pos = self.target_pos
                        self.current_vel = 0.0
                        self.state = "IDLE"
                        self.response_queue.put("2")
                        print("[Arduino RX - SIM] 2")
                        
            if not self.simulate and self.ser.in_waiting > 0:
                response = self.ser.readline().decode('utf-8').strip()
                if response in ["0", "1", "2"]:
                    self.response_queue.put(response)
                    print(f"[Arduino RX] {response}")
                    
            # Keep worker deterministic enough for repeatable focus tests.
            time.sleep(0.005) # Run physics loop at 200Hz

# ==========================================
# 4. FRAME/STEP CORRELATOR
# ==========================================
class CameraSource:
    def __init__(self, use_zmq=False, source="ipc:///tmp/video_feed"):
        """
        Frame source abstraction.

        - ZMQ mode: consume live frames from publisher socket.
        - Video mode: map focus step to deterministic frame index in replay clip.
        """
        self.use_zmq = use_zmq
        
        if self.use_zmq:
            self.context = zmq.Context()
            self.sub_socket = self.context.socket(zmq.SUB)
            self.sub_socket.connect(source)
            self.sub_socket.setsockopt(zmq.SUBSCRIBE, b"video_feed")
            self.sub_socket.setsockopt(zmq.CONFLATE, 1)
            self.total_frames = None
        else:
            self.cap = cv2.VideoCapture(source)
            self.total_frames = int(self.cap.get(cv2.CAP_PROP_FRAME_COUNT))

    def get_frame(self, current_step):
        """
        Return `(frame_index, frame)`.

        In replay mode, `current_step` is converted into a frame index so
        autofocus can be debugged deterministically frame-to-position.
        """
        if self.use_zmq:
            try:
                topic, ts_bytes, shape_bytes, frame_bytes = self.sub_socket.recv_multipart(flags=zmq.NOBLOCK)
                h, w, c = map(int, shape_bytes.decode('utf-8').split(','))
                frame = np.frombuffer(frame_bytes, dtype=np.uint8).reshape((h, w, c))
                return 0, frame # Realtime
            except zmq.Again:
                return 0, None
        else:
            # MAP MOTOR STEP -> EXACT FRAME OF VIDEO
            step_ratio = current_step / TOTAL_MOTOR_STEPS
            frame_idx = int(step_ratio * (self.total_frames - 1))
            frame_idx = max(0, min(frame_idx, self.total_frames - 1))
            
            self.cap.set(cv2.CAP_PROP_POS_FRAMES, frame_idx)
            ret, frame = self.cap.read()
            if not ret:
                return frame_idx, np.zeros((480, 640, 3), dtype=np.uint8) 
            return frame_idx, frame
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

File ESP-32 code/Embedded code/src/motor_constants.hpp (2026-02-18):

#ifndef MOTOR_CONSTANTS_HPP
#define MOTOR_CONSTANTS_HPP

////////////////////////////////////////////////////////////////
/////////// Global Motor constants
////////////////////////////////////////////////////////////////

#define TICKS_PER_REV 48
const int pwm_start_test = 1; // PWM minimal to start test
const int pwm_max_driver = 255;
const int repetitions = 3; // number of time to test minimum PWM
const int8_t quadTable[16] = {0,-1,1,0,1,0,0,-1,-1,0,0,1,0,1,-1,0};

////////////////////////////////////////////////////////////////
/////////// Pin definitions MOTOR DECLINATION (DEC)(BLUE)
////////////////////////////////////////////////////////////////

// Encoder pins
#define DEC_ENC_A 2 //yellow
#define DEC_ENC_B 3 //brown

// BTS7960 Motor Driver
#define DEC_RPWM 6 //green
#define DEC_LPWM 7 //yellow
#define DEC_REN  22 //blue
#define DEC_LEN  23 //orange

// Motor constants
const int DEC_pwm_start_max = 150; // PWM maximal for the calibration test, if the minimum PWM is higher than this value, the test is redone
const double DEC_gearbox = 900.0;
const double DEC_Kp = 25.0;   // Proportional gain
const double DEC_Ki = 0.025;     // Integral gain
const double DEC_Kd = 0.001;   // Derivative gain

////////////////////////////////////////////////////////////////
/////////// Pin definitions MOTOR RIGHT ASCENSION (RA)(ORANGE)
////////////////////////////////////////////////////////////////

// Encoder pins
#define RA_ENC_A 18 //yellow
#define RA_ENC_B 19 //brown

// BTS7960 Motor Driver
#define RA_RPWM 8 //green
#define RA_LPWM 9 //yellow
#define RA_REN  24 //blue
#define RA_LEN  25 //orange

// Motor constants
const int RA_pwm_start_max = 150; // PWM maximal for the calibration test, if the minimum PWM is higher than this value, the test is redone
const double RA_gearbox = 900.0;
const double RA_Kp = 25.0;    // Proportional gain
const double RA_Ki = 0.025;     // Integral gain
const double RA_Kd = 0.001;   // Derivative gain


#endif // MOTOR_CONSTANTS_HPP

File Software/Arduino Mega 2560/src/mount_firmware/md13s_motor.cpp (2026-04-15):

#include "md13s_motor.hpp"

#if defined(STARTRACK_ENABLE_REFACTORED_ARCH)

#include <math.h>

namespace refactored {

/**
 * @brief Constructor for MD13SMotor (PWM+DIR driver with speed control).
 * @param name Motor name (e.g., "Focus")
 * @param encoderId Encoder ID (e.g., MOTOR_FOCUS)
 * @param pins MD13S pins configuration (PWM, DIR, optional inversion)
 * @param positionPid PID tuning for position control during calibration
 * @param speedPid SpeedPidConfig with speed loop tuning and velocity profile settings
 * @param runtime Motion constraints (min/max speed, acceleration, timeout)
 * @param limits Limit switch configuration
 * @param calibration Calibration parameters
 * @param precision Micro-correction settings
 * 
 * Stores both position and speed PID configurations since the motor supports two modes:
 * - POSITION mode during calibration (inherited MotorBase PID control)
 * - SPEED mode during user-commanded focus moves (this class's dual-loop algorithm)
 * 
 * Speed control state initialized to zero:
 * - m_requestedSpeedTicksPerSec: Desired constant speed (set by commandSpeedTicksPerSecond)
 * - m_speedIntegral: Accumulated speed error for PID integral term
 * - m_prevSpeedError: Previous speed error for PID derivative term
 * - m_profileTick: Virtual position moving at constant speed (generates smooth reference)
 * - m_prevSpeedTick: Previous encoder position for velocity calculation
 */
MD13SMotor::MD13SMotor(const char* name,
                       MotorId encoderId,
                       const Md13sPins& pins,
                       const PidConfig& positionPid,
                       const SpeedPidConfig& speedPid,
                       const MotorRuntimeConfig& runtime,
                       const LimitConfig& limits,
                       const CalibrationConfig& calibration,
                       const PrecisionConfig& precision)
    : MotorBase(name, encoderId, positionPid, runtime, limits, calibration, precision),
      m_pins(pins),
      m_speedPid(speedPid),
      m_requestedSpeedTicksPerSec(0.0f),  // No speed requested initially
      m_speedIntegral(0.0f),               // Speed PID integral accumulator
      m_prevSpeedError(0.0f),              // Previous speed error for derivative
      m_filteredActualSpeed(0.0f),         // Filtered speed estimate
      m_profileTick(0.0f),                 // Virtual position tracking
      m_prevSpeedTick(0),                  // Base position for velocity calc
      m_speedLog(),
      m_speedLogCount(0),
      m_speedLogActive(false),
      m_speedLogStartMs(0),
      m_speedLogLastSampleMs(0) {}

/**
 * @brief Command motor to move at constant speed to a target position.
 * @param targetTicks Final position where motor should stop
 * @param ticksPerSecond Desired constant speed in encoder ticks/second
 * @return true if command accepted and speed control started
 * 
 * Validate command through position check (ensures target is in valid range),
 * then initiate dual-loop speed control:
 * 1. Validates speed is positive (negative used for direction only)
 * 2. Uses base class position validation to check target is in range
 * 3. Switches motion mode from POSITION to SPEED
 * 4. Resets speed PID state for clean start (zero integral and derivative)
 * 5. Initializes velocity profile at current position
 * 
 * After return, the motor will accelerate/decelerate smoothly to requested speed,
 * then maintain that speed while moving toward targetTicks, with automatic slowdown
 * near the target to prevent overshoot (configured in SpeedPidConfig.slowdownWindowTicks).
 */
bool MD13SMotor::commandSpeedTicksPerSecond(long targetTicks, float ticksPerSecond) {
  // Validate speed is positive (direction determined by target vs current)
  if (ticksPerSecond <= 0.0f) {
    return false;  // Speed must be positive
  }
  
  // Validate target position is in valid range (not beyond limits, not during calibration, etc.)
  if (!commandPositionTicks(targetTicks)) {
    return false;  // Position validation fails
  }

  // Switch to speed control mode
  m_requestedSpeedTicksPerSec = ticksPerSecond;  // Store target speed
  m_motionMode = MotionMode::SPEED;              // Switch motion mode
  m_state = MotorState::SPEED_MOVING;            // Set state machine to moving
  
  // Reset speed PID state for clean start without accumulated integral windup
  m_speedIntegral = 0.0f;
  m_prevSpeedError = 0.0f;
  m_filteredActualSpeed = 0.0f;
  
  // Initialize velocity profile: starts at current position and moves at constant speed
  m_profileTick = static_cast<float>(readTicks());  // Virtual position = actual position
  m_prevSpeedTick = readTicks();                    // Base for velocity delta calculation
  resetSpeedLog(millis());                          // Start trace capture for this speed move
  
  // Reset position PID controller (used for position assist component)
  resetController();
  
  return true;
}

/**
 * @brief Update speed-loop PID gains at runtime.
 * @param kp New proportional gain
 * @param ki New integral gain
 * @param kd New derivative gain
 * @return true if gains are valid and applied
 */
bool MD13SMotor::setSpeedPidGains(float kp, float ki, float kd) {
  if (!isfinite(kp) || !isfinite(ki) || !isfinite(kd)) {
    return false;
  }
  if (kp < 0.0f || ki < 0.0f || kd < 0.0f) {
    return false;
  }
  m_speedPid.kp = kp;
  m_speedPid.ki = ki;
  m_speedPid.kd = kd;
  m_speedIntegral = 0.0f;
  m_prevSpeedError = 0.0f;
  resetController();
  return true;
}

void MD13SMotor::onTargetReached(unsigned long nowMs, long currentTicks) {
  if (readMotionMode() == MotionMode::SPEED) {
    dumpSpeedLog(nowMs, currentTicks);
  }
}

void MD13SMotor::resetSpeedLog(unsigned long nowMs) {
  m_speedLogCount = 0;
  m_speedLogActive = true;
  m_speedLogStartMs = nowMs;
  m_speedLogLastSampleMs = nowMs;
}

void MD13SMotor::maybeAppendSpeedLog(unsigned long nowMs,
                                     float desiredTicksPerSec,
                                     float actualTicksPerSec) {
  if (!m_speedLogActive) return;
  if ((nowMs - m_speedLogLastSampleMs) < m_speedPid.speedLogSamplePeriodMs) return;
  m_speedLogLastSampleMs = nowMs;
  if (m_speedLogCount >= kSpeedLogCapacity) return;

  const unsigned long elapsedMs = nowMs - m_speedLogStartMs;
  m_speedLog[m_speedLogCount].tMs = static_cast<uint16_t>((elapsedMs > 65535UL) ? 65535UL : elapsedMs);
  m_speedLog[m_speedLogCount].desiredTicksPerSec = static_cast<int16_t>(lroundf(desiredTicksPerSec));
  m_speedLog[m_speedLogCount].actualTicksPerSec = static_cast<int16_t>(lroundf(actualTicksPerSec));
  ++m_speedLogCount;
}
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

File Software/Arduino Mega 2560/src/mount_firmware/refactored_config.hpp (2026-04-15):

#ifndef REFACTORED_CONFIG_HPP
#define REFACTORED_CONFIG_HPP

#include <Arduino.h>

namespace refactored {

enum class MotorId : uint8_t {
  AXIS_DEC = 0,
  AXIS_RA = 1,
  AXIS_FOC = 2,
  COUNT = 3
};

enum class SwitchId : uint8_t {
  SW1 = 0,
  SW2 = 1,
  SW3 = 2,
  SW4 = 3,
  SW5 = 4,
  SW6 = 5,
  SW7 = 6,
  SW8 = 7,
  SW9 = 8,
  SW10 = 9,
  COUNT = 10
};

namespace pins {

// DEC encoder + BTS7960 pins
static const uint8_t DEC_ENC_A = 2;
static const uint8_t DEC_ENC_B = 3;
static const uint8_t DEC_RPWM = 6;
static const uint8_t DEC_LPWM = 7;
static const uint8_t DEC_REN = 22;
static const uint8_t DEC_LEN = 23;

// RA encoder + BTS7960 pins
static const uint8_t RA_ENC_A = 19;
static const uint8_t RA_ENC_B = 18;
static const uint8_t RA_RPWM = 9;
static const uint8_t RA_LPWM = 8;
static const uint8_t RA_REN = 24;
static const uint8_t RA_LEN = 25;

// Focus encoder + MD13S pins
static const uint8_t FOC_ENC_A = 50;  // Port B bit 2
static const uint8_t FOC_ENC_B = 51;  // Port B bit 3
static const uint8_t FOC_DIR = 10;
static const uint8_t FOC_PWM = 11;

// Limit switch pins (active-low)
static const uint8_t SW1 = A8;
static const uint8_t SW2 = A9;
static const uint8_t SW3 = A10;
static const uint8_t SW4 = A11;
static const uint8_t SW5 = A12;
static const uint8_t SW6 = A13;
static const uint8_t SW7 = A14;
static const uint8_t SW8 = A15;
static const uint8_t SW9 = 12;   // Port B bit 6
static const uint8_t SW10 = 13;  // Port B bit 7

}  // namespace pins

// Fast quadrature decoding table for 2-bit Gray transitions.
static const int8_t QUAD_TABLE[16] = {
    0, -1, 1, 0,
    1, 0, 0, -1,
    -1, 0, 0, 1,
    0, 1, -1, 0};

}  // namespace refactored

#endif  // REFACTORED_CONFIG_HPP

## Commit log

2026-01-15 Add image center detection script and test image
    Introduced main.py for detecting and marking the center of the largest contour in a grayscale image using OpenCV. Added a sample test image and updated requirements.txt to include opencv-python.
2026-01-16 Switch from static image to real-time webcam processing
    Replaces static image analysis with real-time video capture from the webcam. Adds live contour detection, center and diameter calculation, and overlays results on the video stream. Exits loop on 'q' key press and properly releases the camera resource.
2026-01-27 Add initial ESP-32 embedded and Python communication code
    Added PlatformIO project structure for ESP-32, including .gitignore, configuration, and a basic Arduino sketch that echoes serial messages with an ACK prefix. Also added a Python script to send and r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
2026-01-27 Add motor control request function for ESP-32
    Introduced Motor enum and send_request_motor function to send motor position requests to ESP-32 and handle acknowledgments. Updated main loop to demonstrate motor control requests and improved serial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
2026-01-28 Add motor control and encoder handling for ESP32
    Replaced Mega2560 config with ESP32 in platformio.ini. Implemented encoder reading, BTS7960 motor driver control, and basic PID logic in main.cpp. Enhanced serial command parsing and response. Updated Python script for improved ACK handling and adjusted test positions and serial port.
2026-01-28 Refactor motor control and add constants header
    Moved motor and encoder constants to a new motor_constants.hpp file for better organization and maintainability. Updated main.cpp to use the new constants, refactored variable names for clarity, and 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
2026-01-28 Refactor serial communication and update motor constants
    Improved serial communication in main.py by introducing a background thread and queue for asynchronous message handling, replacing direct serial reads. Updated motor constants in motor_constants.hpp 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
2026-01-30 Update motor pin mappings and Python control loop
    Added color-coded comments to motor pin definitions and updated pin assignments for RA motor in motor_constants.hpp. Modified main.py to incrementally update the target angle for the RIGHT_ASCENSION motor in a loop, replacing previous fixed-angle commands.
    [motor_constants.hpp]
2026-02-03 Add ESP32-C3 MPU6050 accelerometer project
    Add a new PlatformIO project for ESP32-C3 to read an MPU6050 accelerometer. New files: .gitignore, platformio.ini (esp32-c3-devkitm-1, Arduino framework, USB build flags, Adafruit MPU6050/Unified Sen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
2026-02-03 Add Messier data, reader, ASI recorder
    Add Messier catalog files (CSV and JSON) and a messier_reader.py to load Skyfield Star objects for catalog objects. Integrate CSV loading into Movement/src/main.py (add messier dict and isVisible hel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
    [messier_qc.csv]
2026-02-03 Add RA motor support and PID + calibration
    Extend motor control to support a second (RA) motor and improve PID control and calibration. Key changes:
    - Add RA-specific encoder state, ISR, drive, reading, PID state and update functions.
    - Split DEC drive/encoder functions and refactor update_motor into DEC_update_motor and RA_update_motor; combined update_motor calls both.
    - Add integral (Ki) term with anti-windup for both motors and reset integral on new targets.
    - Replace single minimal-PWM detection with calibrate_minimum_PWM() that tests DEC and RA separately and stores DEC_pwm_min_real and RA_pwm_min_real.
    - Update setup() to initialize RA hardware, attach RA interrupts, and configure PWM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
    [motor_constants.hpp]
2026-02-03 DEC motor functionning, RA motor not working
    Adjust motor control parameters and improve calibration/debugging:
    - Set initial minimal PWM for both motors to 150.
    - Enable REN/LEN lines in DEC/RA drive functions before writing PWM.
    - Change RA driver PWM pin (RA_RPWM) from 15 to 17.
    - Increase RA PID proportional gain (RA_Kp) from 15.0 to 100.0.
    - Improve minimum-PWM detection: add serial logging, increase sample delay, raise motion threshold, and alter RA search start value.
    - Simplify calibration loop to use single detection per repetition and comment out retest warnings.
    - Add debug Serial prints in DEC/RA update functions and initialize prevTime values in setup to avoid large initial dt.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
    [motor_constants.hpp]
2026-02-06 Update ESP32 board, PWM pin, and COM port
    Change PlatformIO environment to esp32_wroom32u and use the esp32dev board (platformio.ini). Adjust motor wiring and logic: RA_LPWM pin changed from 18 to 15 in motor_constants.hpp, and RA_find_minimum_PWM now starts from pwm_start_test instead of a hardcoded 400 (src/main.cpp). Remove inline debug markers in encoder reads. Update host serial port in the Python helper from COM5 to COM9 (Python_part/main.py). These edits align the build config with the target board, fix pin mapping, and use the configured PWM start value while updating the serial connection used for the ESP32.
    [motor_constants.hpp]
2026-02-11 Working version!! Keyboard control; refine calibration & pins
    Add interactive keyboard control to Python client and harden motor calibration in firmware.
    Python: import msvcrt and add a non-blocking keyboard loop to send WASD controls and adjust speed with arrow keys (send_request_motor helper added). The previous continuous test loop is commented out.
    Firmware (ESP32): change DEC_LPWM and RA_LPWM pin assignments, add DEC_pwm_start_max and RA_pwm_start_max, and set RA gearbox to 900. Improve minimum PWM detection by printing motor-specific test messages, shortening delays, retrying if PWM exceeds start_max (with user guidance), reordering calibration loops to collect DEC then RA, and print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
    [motor_constants.hpp]
2026-02-11 Use discrete speed presets with index
    Replace continuous speed_factor stepping with a discrete list of calibrated speed_values and a speed_index. Initialize speed_factor from speed_values[speed_index] and remove speed_step/min/max. Up/down arrow handling now increments/decrements the index within bounds and updates speed_factor accordingly, providing stable, repeatable speed presets.
2026-02-12 Add Arduino Mega Shield KiCad project
    [Arduino_Mega_Shield.kicad_pcb, Arduino_Mega_Shield.kicad_sch]
2026-02-15 Update KiCad PCB (Pololu A4988) and ESP32 code
    Replace Arduino Mega shield footprint with a Pololu A4988 breakout footprint and reorganize PCB item positions/annotations (silkscreen, fab, footprint properties, net index adjustments). Add several Arduino_Mega_Shield backup zip files. Also include changes to ESP-32 embedded code (src/main.cpp and src/motor_constants.hpp) — likely motor/driver-related updates to match the hardware footprint changes.
    [Arduino_Mega_Shield.kicad_pcb, Arduino_Mega_Shield.kicad_sch]
2026-02-16 Rename analyse->find_center and add focus_score
    Refactor image_test.py: rename analyse to find_center and convert comments, prints and variable names to English. Simplify visualization/return (now returns only center and draws a single center marker instead of diameter/circle). Fix image read error message and contour spelling. Add focus_score(image_path) which computes a masked, downscaled Laplacian-variance focus metric and prints the raw score. Update __main__ to exercise the new functions on sample images.
2026-02-17 Revise KiCad PCB footprints and add backups
    Large update to the Arduino_Mega_Shield KiCad project: modified .kicad_pcb/.kicad_prl/.kicad_pro/.kicad_sch to replace and update connector footprints (JST XH, pin headers), adjust pad shapes/drills, 3D model refs, net names and UUIDs. Project housekeeping: removed autosave and lock files, renamed an autosave schematic to a .kicad_sch-bak, added multiple Arduino_Mega_Shield-backups ZIPs and added freerouting.rules. These changes consolidate footprint fixes and clean up temporary files prior to routing.
    [Arduino_Mega_Shield.kicad_pcb, Arduino_Mega_Shield.kicad_sch]
2026-02-18 Avancement on the electric shemas and some fixe on the PCB
    [Arduino_Mega_Shield.kicad_pcb, Arduino_Mega_Shield.kicad_sch]
2026-02-18 Restructure Movement & add Vision scripts
    Large refactor and feature additions: movement module reorganized (removed legacy messier_reader.py and src/main.py) and new files added under Software/Movement/src: catalog.py (central object catalo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
2026-02-18 Some mast modification before changing for a Arduino Mega
    [Arduino_Mega_Shield.kicad_pcb]
2026-02-18 Change the code to work on a Arduino Mega and change the timers to be silent
    Switch project from ESP32 to ATmega2560 (PlatformIO env changed to megaatmega2560). Replace ESP32 ledc PWM APIs with Arduino analogWrite/pinMode and configure timer prescalers (TCCRnB) for quieter PWM. Update encoder/motor pin mappings for the Mega, remove IRAM_ATTR from ISRs, and reduce PWM range to 8-bit (max 255) with updated calibration start/step/max values. Lower PID gains for both motors, decrease loop delay (20ms -> 5ms), and update the host serial port in the Python script (COM9 -> COM8). These changes adapt the code and tuning for the Mega hardware and its PWM characteristics.
    [motor_constants.hpp]
2026-02-23 Avancement in the PCB design
    [Arduino_Mega_Shield.kicad_pcb, Arduino_Mega_Shield.kicad_sch, freerouting.dsn]
2026-02-23 PCB trace, but not verified
    [Arduino_Mega_Shield.kicad_pcb, freerouting.dsn]
2026-02-24 First revision of the PCB
    [Arduino_Mega_Shield.kicad_pcb]
2026-02-24 Create electrical schema of the circuit
    [Arduino_Mega_Shield.step]
2026-02-24 Refactor movement control and update vision
    Recenter.py: Large refactor of movement/control logic — renamed and uppercased constants, added Skyfield timescale, introduced MOVEMENTSTATE enum, implemented raTracking, rotateXYtoAltAz, moveManually, moveToTarget and a simple main loop. Improved joystick input limits, earth-rotation compensation, RA/Dec handling and pixel-to-angle calculations; cleaned up coordinate transform matrix and logging.
    astrononic_function.py: Minor cleanup around main() and visible-catalog printing (whitespace/comment adjustments).
    recording_asi.py: Adjusted ASI camera defaults (gain/exposure), switched to RAW16 for deep-sky capture and fixed frame dtype/reshape to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
2026-02-24 Add Jupiter video processing script
    Adds Software/Vision/src/video_test.py: a simple OpenCV pipeline that downsamples frames, thresholds and finds largest contour to locate a center, computes focus via Laplacian variance (with a rollin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
2026-03-01 Avancement on the silkscreen of the PCB
    [Arduino_Mega_Shield.kicad_pcb, Arduino_Mega_Shield.kicad_sch]
2026-03-01 Final version of the PCB
    [Arduino_Mega_Shield.kicad_pcb]
2026-03-07 Refactor of the Arduino code to improve readability and debugging
    [Arduino_Mega_Shield.kicad_pcb, bom.csv, designators.csv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]
2026-03-07 Add FOCUS motor control and switches support
    Implement FOCUS motor driver, encoder handling, PID control and calibration; add hardware switch handling via a new switches module. Updated constants.hpp with FOCUS pin/gear/PID settings, extra moto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
2026-03-10 Enhance FOCUS motor control and tuning
    Adjust FOCUS control parameters and add safety/behavior changes.
    - constants.hpp: set FOCUS_gearbox to 75.0 and increase FOCUS_Kp to 1.0 to correct gearing and strengthen proportional control.
    - motors.cpp:
    - In FOCUS_drive_motor invert/constrain PWM to match wiring and prevent movement into switch by zeroing PWM when switch1 is triggered.
    - Increase delay in FOCUS_find_minimum_PWM() calibration from 200ms to 400ms.
    - Call FOCUS_update_motor() from update_motor() so focus is updated together with other axes.
    - Compute target tick values directly from the passed degree argument in set_motor_* functions.
    - main.cpp:
    - Move zeroing of motors to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
2026-03-10 Enforce limit switches and adjust motor gains
    Add safety checks and clarity around limit switches, enable motor drivers, and tweak control gains:
    - constants.hpp: set FOCUS_Ki from 0.0 to 0.5 and add comments for SWITCH_* pins (noting active-low, GND when triggered).
    - main.cpp: add comments about ISR and update_motor importance; restore delay(5) and remove duplicate update call.
    - motors.cpp: ensure motor driver enable pins are asserted, constrain PWM, and stop RA/DEC motors when a limit switch would be violated; invert focus switch logic to match active-low wiring; add small clarifying comments.
    - switchs.cpp: initialize switch flags to true (reflecting INPUT_PULLUP default), and make ISR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
2026-03-11 NOT WORKING Detect RA angle range; reduce start PWM
    Lowered PWM start maxima (DEC/RA/FOCUS) from 150 to 120 to reduce calibration drive power. Implemented RA angle-range detection: added RA_find_angle_range(), global min/max angle variables, and prototypes; added find_angle_range() wrapper and call to RA_find_angle_range() in setup to determine encoder limits via limit switches. motors.hpp now includes constants.hpp and declares the new externs/functions. Also commented out the existing automatic minimum-PWM calibration loop in motors.cpp (calibrate_minimum_PWM) to avoid running the previous calibration while range detection is being used.
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2026-03-22 The RA calibration is almost working
    Refine motor calibration routines for RA/DEC and add focus calibration. Changes include: calling RA_find_angle_range() from setup; removing unused static vars; tightening encoder centering threshold and reducing delay between switch passages for faster calibration; ensuring motors are stopped and encoder counts reset after centering; computing middle tick for RA and DEC and setting target ticks; inverting/fixing switch-check logic during homing; implementing FOCUS_find_angle_range(); and adding helpers set_motor_ra_ticks() and set_motor_focus_ticks(). Miscellaneous whitespace/cleanup included.
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2026-03-28 improve readability of electrical shematic
    [Arduino_Mega_Shield.kicad_sch]
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2026-03-29 Add 3D STL parts for gearboxes and mounts
    Add numerous STL assets for 3D printing, organized under DECLIMATION GEARBOX, RIGHT ASCENSION GEARBOX GEARBOX, and OTHER. Includes cycloidal disks, eccentric shafts, rotors/stators, motor mounts, top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
    [BAR HOLDER.stl, BOTTOM STATOR.stl, COUNTER WEIGHT HOLDER.stl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]
2026-03-29 First commit for integration with working calibration
    Introduce a refactored build env and runtime improvements for motor control: add STARTRACK_ENABLE_REFACTORED_ARCH PlatformIO env and main_refactored build filters. Enhance MD13S motor with filtered speed estimate, runtime speed PID tuning, speed trace logging, snap-to-position handover, derivative clamping, bounded position-assist, stiction handling, and PWM saturation. Extend MotorBase with runtime position PID updates, safer open-loop PWM capping, improved single-switch homing flow, end-stop recovery for SPEED mode, and target-tolerance handling with onTargetReached callbacks. Add staged calibration launcher in MountController (configur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
    [astronomic_operator.py, md13s_motor.cpp, motor_base.cpp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]
2026-03-30 time fix i think
    [astronomic_operator.py]
2026-03-31 Few modification still many issues (position joystick motor killing battery, etc.)
    [astronomic_operator.py, mount_controller.cpp, refactored_config.hpp]
2026-04-01 Add PowerSchema For estimating battery life
    [Arduino_Mega_Shield.kicad_pcb, Arduino_Mega_Shield.kicad_sch, Arduino_Mega_Shield.step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]
2026-04-01 Add and reorganize 3D print STL files
    Add multiple new STL assets (focus parts, tripod bracket parts, electrical skeleton components, and a HOLDER) and include STAR-TRACK (ALL PARTS).zip. Reorganize existing STL files into numbered subfo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
    [BAR HOLDER.stl, BOTTOM STATOR.stl, COUNTER WEIGHT HOLDER.stl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]
2026-04-01 Rename 3D print files to include quantities
    Batch-rename STL files across '007 - GEARBOX JOINT', '014 - CYCLOIDAL GEARBOX', and '015 - ELECTRICAL SKELETON' to include quantity indicators (e.g. '(2X)', '(4X)', '(6X)'). The renames are identical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
    [(2X) CYCLOIDAL DISK 23.stl, (2X) SIDE COVER PLATE.stl, (2X) TOP CAP.stl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]
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2026-04-02 Fixing joystick not working when no target.
    [astronomic_operator.py]
2026-04-02 Fix joystick speed mapping and DEC scaling
    Swap the speed arguments passed to x_y_to_ha_dec so joystick X/Y map to the intended DEC/RA speeds in both manual-input code paths, and adjust manual_speed_max_dec_deg_s to manual_speed_max_ra_deg_s / 23.0 (was /24.0). This corrects an incorrect axis-to-coordinate mapping and restores the intended DEC responsiveness.
    [astronomic_operator.py]
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2026-04-09 Clean Up and Refactor of file system
    [messier_qc.csv]
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2026-04-17 Update electric schematic
    Replace Hardware/Electric shematic.png with an updated binary image. The PNG file has been changed to a new version of the electrical schematic diagram.
